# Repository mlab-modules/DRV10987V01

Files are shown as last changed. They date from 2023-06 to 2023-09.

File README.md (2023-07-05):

# DRV10987V01 BLDC motor controller
This MLAB module features the [DRV10987](https://www.ti.com/lit/ds/symlink/drv10987.pdf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) controller by Texas Instruments, designed for sensorless operation of Brushless DC ([BLDC](https://en.wikipedia.org/wiki/Brushless_DC_electric_motor)) and Permanent Magnet Synchronous Motors ([PMSM](https://en.wikipedia.org/wiki/Synchronous_motor#Permanent-magnet)).

 

### Description
The DRV10987 is a three-phase, sensorless, brushless DC motor driver that carries out all necessary functions for ordinary operation of brushless motors. It is a powerful solution that is compact and easy to implement.

This module offers a straightforward way to integrate this potent driver into your project, whether you're a hobbyist, a researcher, or a professional engineer.
Specifications

 *   Power supply ranging from 6.2V to 28V for driving motors with diverse voltage requirements
 *   Provide a continuous current of 2A and peak current of 3A
 *   Can control motor speed based on PWM, analogue, or digital (I2C) input
 *   Contains an FG pin that can be used to monitor motor rotation
 *   Integrated Buck converter at 5V and 100mA for powering peripheral devices
 *   Brushless design that minimizes wear and enables quiet operation
 *   Sensorless commutation for easy installation and maintenance
 *   PWM input frequency up to 100kHz
 *   Communication via I2C interface
 *   Built-in functions for overload and overheat protection

### Applications

This MLAB module equipted with the DRV10987 controller is highly versatile and is ideal for several applications where efficient and reliable control of smaller motors is required. Some of the primary use cases include:

 * **Small Drones and RC Models**: Due to its compact size and efficient operation, the DRV10987 controller is commonly used in the design of smaller drones and radio-controlled models. These vehicles require precise, reliable motor control for stabilization and maneuverability, which this module can adequately provide.
 * **Robotic Systems**: In robotics, precise control of motor speed and direction is essential. The DRV10987 controller's ability to regulate speed based on PWM, analogue, or digital (I2C) input makes it suitable for smaller robotic applications, including hobbyist robots, robotic toys, and educational kits.
 * **Home Appliances**: Small electrical appliances, such as desk fans, can make use of the DRV10987 controller for efficient and quiet operation. The controller's brushless design minimizes wear, which enhances the lifespan and user experience of these devices.
 * **Hobby Projects**: For hobbyists and DIY enthusiasts, this module with the DRV10987 controller is a great tool for various projects requiring control of smaller BLDC or PMSM motors. Its ease of use and versatility make it a valuable component in prototyping and experimentation.

### Installation and Integration
Our MLAB modules are designed to be as straightforward as possible for integration into your project. To connect this module, you only need a standard power supply and an I2C bus for communication with the control system.

### DRV10987

The DRV10987 from Texas Instruments is a three-phase, sensorless motor driver engineered for brushless DC (BLDC) and Permanent Magnet Synchronous Motors (PMSM). It is designed to handle all necessary functions for the routine operation of brushless motors. Capable of delivering a continuous current of 2A and a peak current of 3A, the DRV10987 can control motor speed based on PWM, analogue, or digital (I2C) input. This versatile chip also features an FG pin for monitoring motor rotation and has an integrated Buck converter at 5V and 100mA for powering peripheral devices. With built-in functions for overload and overheat protection, the DRV10987 represents a robust, compact, and efficient solution for a range of applications that require reliable motor control.

Detailed technical information about the DRV10987 controller can be found in the datasheet, available on the manufacturer's website [here](https://www.ti.com/lit/ds/symlink/drv10987.pdf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).

### Schematics



## Availability and Pricing

The MLAB module DRV10987V01 with the DRV10987 controller is commercially produced and sold by Universal [Scientific Technologies s.r.o](https://ust.cz/). For information on availability and pricing, please contact the company directly via email at [info@ust.cz](mailto:info@ust.cz). They will be able to provide the most accurate and up-to-date information regarding your purchase inquiries.

### Conclusion
Regardless of whether you're building a sophisticated robotic system or a simple hobbyist project, this module with the DRV10987 controller from Texas Instruments is a powerful tool for sensorless control of BLDC and PMSM motors.

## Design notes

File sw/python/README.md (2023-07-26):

# Python control class for DRV10987 BLDC driver

This class provides a convenient interface to control a BLDC motor using the DRV10987V01 module, which contains the Texas Instruments DRV10987 motor driver IC. It allows configuration of various parameters and registers to control the motor speed, current, and other functionalities.

The DRV10987V01 module is designed for use with 3-phase sensorless BLDC motors, and this class
simplifies the communication and configuration process, making it easier to drive the motor.

Before using this class, make sure you have properly initialized the communication interface to
communicate with the DRV10987 module using the SMBus interface. For example, you can use the
USBI2C01 module (https://www.mlab.cz/module/USBI2C01) to connect your computer to the driver.

Note:
- Connect the DRV10987V01 module to your motor and power supply according to the module's specifications.
- The methods of this class assume that you have already set up the communication interface (SMBus) correctly.

Example usage:
drv = MLAB_DRV10987()
drv.configure_CONFIG1(RMValue=0b0111011, odpor_vinuti=1)
drv.set_SpeedCtrl(speed=50)  # Set motor speed to 50% (default override=True)
drv.enable_motor()  # Enable motor output
drv.print_status_registers()  # Print the current status registers
drv.disable_motor()  # Disable motor output
"""

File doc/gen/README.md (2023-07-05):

# PCB

Board size: 50.29x40.13 mm (1.98x1.58 inches)

- This is the size of the rectangle that contains the board
- Thickness: 1.6 mm (63 mils)
- Material: FR4
- Finish: None
- Layers: 2
- Copper thickness: 35 µm

Solder mask: TOP / BOTTOM

- Color: Green

Silk screen: TOP / BOTTOM

- Color: White

Stackup:

| Name | Type | Color | Thickness | Material | Epsilon_r | Loss tangent |
|---|---|---|---|---|---|---|
| F.SilkS | Top Silk Screen | | | | | |
| F.Paste | Top Solder Paste | | | | | |
| F.Mask | Top Solder Mask | | 10 | | | |
| F.Cu | copper | | 35 | | | |
| dielectric 1 | core | | 1510 | FR4 | 4.5 | 0.020 |
| B.Cu | copper | | 35 | | | |
| B.Mask | Bottom Solder Mask | | 10 | | | |
| B.Paste | Bottom Solder Paste  | | | | | |
| B.SilkS | Bottom Silk Screen | | | | | |

# Important sizes

Clearance: 0.2 mm (8 mils)

Track width: 0.25 mm (10 mils)

- By design rules: 0.2 mm (8 mils)

Drill: 0.3 mm (12 mils)

- Vias: 0.5 mm (20 mils) [Design: 0.3 mm (12 mils)]
- Pads: 0.3 mm (12 mils)
- The above values are real drill sizes, they add 0.1 mm (4 mils) to plated holes (PTH)

Via: 0.8/0.4 mm (31/16 mils)

- By design rules: 0.4/0.2 mm (16/8 mils)
- Micro via: yes [0.2/0.1 mm (8/4 mils)]
- Buried/blind via: yes
- Total: 46 (thru: 46 buried/blind: 0 micro: 0)

Outer Annular Ring: 0.13 mm (5 mils)

- By design rules: 0.13 mm (5 mils)

Eurocircuits class: 6D
- Using min drill 0.3 mm for an OAR of 0.13 mm

# General stats

Components count: (SMD/THT)

- Top: 0/11 (THT)
- Bottom: 19/0 (SMD)

Defined tracks:

- 0.3 mm (12 mils)
- 0.5 mm (20 mils)

Used tracks:

- 0.25 mm (10 mils) (2) defined: no
- 0.3 mm (12 mils) (67) defined: yes
- 0.4 mm (16 mils) (7) defined: no
- 0.5 mm (20 mils) (15) defined: yes

Defined vias:

Used vias:

- 0.8/0.4 mm (31/16 mils) (Count: 46, Aspect: 2.0 A) defined: no

Holes (excluding vias):

- 0.2 mm (8 mils) (15)
- 0.89 mm (35 mils) (36)
- 1.15 mm (45 mils) (5)
- 3.0 mm (118 mils) (4)

Oval holes:

Drill tools (including vias and computing adjusts and rounding):

- 0.3 mm (12 mils) (15)
- 0.5 mm (20 mils) (46)
- 1.0 mm (39 mils) (36)
- 1.25 mm (49 mils) (5)
- 3.1 mm (122 mils) (4)

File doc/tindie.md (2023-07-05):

If you're seeking a compact, efficient, and easy-to-integrate solution for controlling smaller Brushless DC (BLDC) or Permanent Magnet Synchronous Motors (PMSM), then our MLAB module with the DRV10987 controller from Texas Instruments is for you!

This highly versatile module is perfect for hobbyists, DIY enthusiasts, researchers, and engineers alike. It's designed to handle a continuous current of 2A and a peak current of 3A, making it perfect for smaller-scale applications.

Here's what you can expect from this module:

 * A power supply range from 6.2V to 28V, catering to motors with diverse voltage requirements
 * Flexibility in speed control, with support for PWM, analogue, or digital (I2C) input
 * An integrated Buck converter at 5V and 100mA, perfect for powering peripheral devices
 * An FG pin for convenient monitoring of motor rotation
 * Built-in overload and overheat protection, ensuring safe and reliable operation

Whether you're building a small drone, designing a compact robotic system, working on home appliances, or just experimenting with different projects, this module provides the reliable motor control you need.

And for those interested in medical devices, smaller-scale HVAC systems, or industrial automation applications, this module can be an essential part of your project, offering smooth, precise, and efficient motor control.

Our MLAB module with the DRV10987 controller is not only powerful but also straightforward to integrate into your project. It requires a standard power supply and an I2C bus for communication with the control system. You'll appreciate its ease of use and the versatility it brings to your projects.

Get your hands on our MLAB module with the DRV10987 controller and explore the world of efficient and reliable motor control today.

## Documentation

For detailed information, usage examples, and troubleshooting tips, you can access the official documentation of the MLAB DRV10987V01 module. It's located in our official GitHub repository. Here you'll find comprehensive materials to guide you in harnessing the full potential of this controller module. Please visit the repository at [GitHub](https://github.com/mlab-modules/DRV10987V01) to explore the documentation. This resource will greatly assist both beginners and experienced users in their journey with this versatile module. Let our resources guide your project to success.

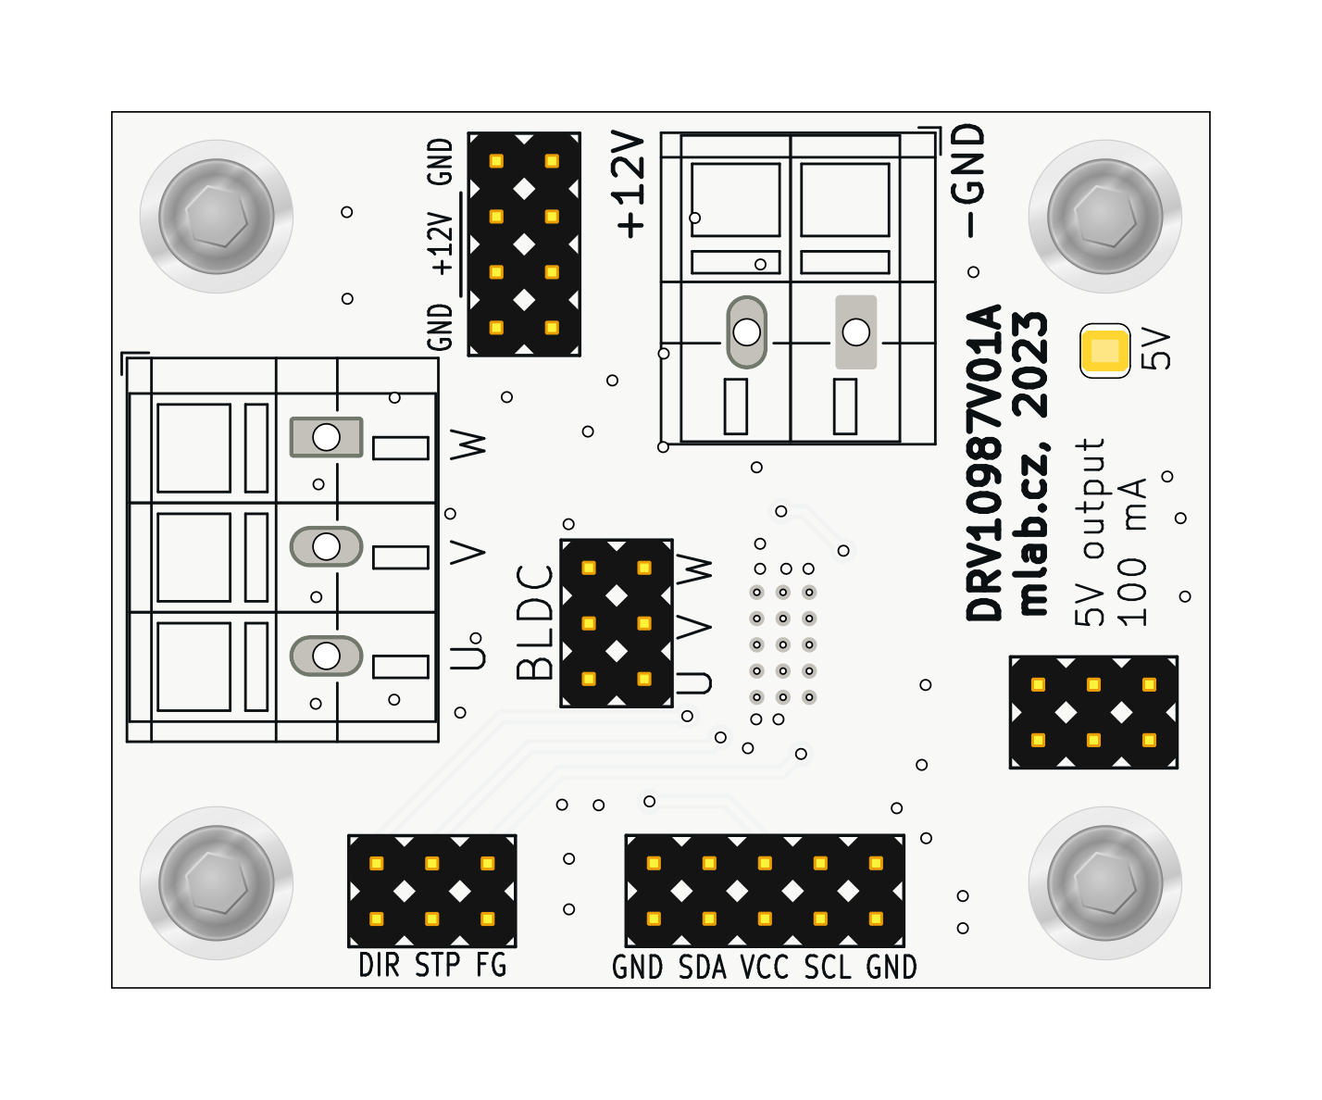
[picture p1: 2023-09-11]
doc/gen/img/DRV10987V01-top.png

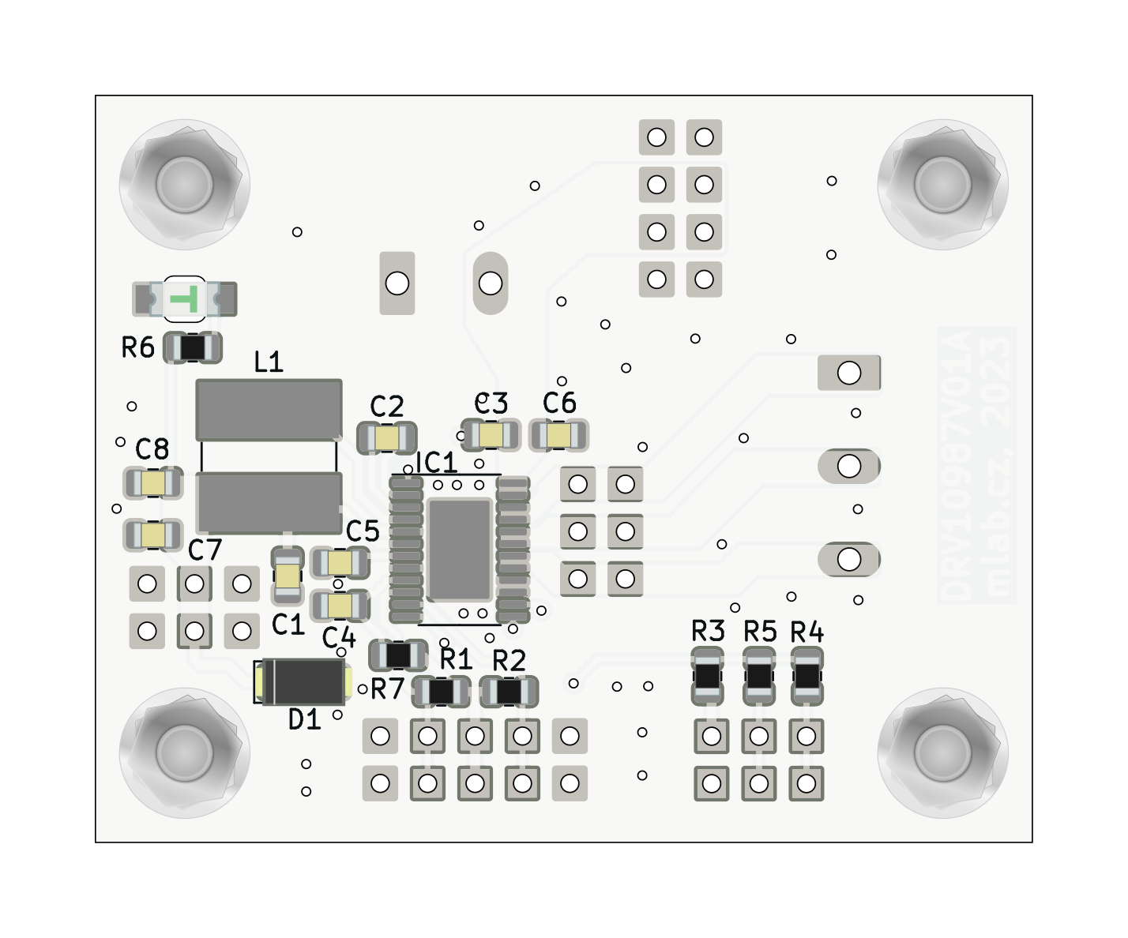
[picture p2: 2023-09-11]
doc/gen/img/DRV10987V01-bottom.png

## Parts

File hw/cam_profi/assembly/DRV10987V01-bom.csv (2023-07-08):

Component | Description | Part | References | Value | Footprint | Quantity Per PCB | Datasheet | ust_id | arrow part number | arrow price/stock | height | manufacturer_name | manufacturer_part_number | mouser part number | mouser price/stock
1 | Unpolarized capacitor, small symbol | C_Small | C2 | 10nF | C_0805_2012Metric | 1 | ~ | 5c70984712875079b91f8b49
2 | Unpolarized capacitor, small symbol | C_Small | C3 | 100nF | C_0805_2012Metric | 1 | ~ | 5c70984712875079b91f8b4c
3 |  | C_Small-Device-ISM02A-rescue | C8 | 100nF | C_0805_2012Metric | 1 |  | 5c70984712875079b91f8b4c
4 | Unpolarized capacitor, small symbol | C_Small | C4C5 | 1uF | C_0805_2012Metric | 2 | ~ | 5c70984712875079b91f8b50
5 | Unpolarized capacitor, small symbol | C_Small | C1C6 | 10uF | C_0805_2012Metric | 2 | ~ | 5c70984712875079b91f8b53
6 |  | C_Small-Device-ISM02A-rescue | C7 | 10uF | C_0805_2012Metric | 1 |  | 5c70984712875079b91f8b53
7 |  | D_ZENER-MLAB_D | D1 | BZV55C-5,6V | D_SMA | 1 |  | 5c70984512875079b91f88b2
8 | Light emitting diode | LED | D2 | GREEN | LED_1206_2 | 1 | ~ | 5c70984412875079b91f8895
9 | 12-V, 3-Phase, Sensorless BLDC Motor Controller | DRV10975PWPR | IC1 | DRV10987DPWPR | TSSOP-24_4.4x7.8mm_P0.65mm_PowerPAD | 1 | https://www.ti.com/lit/ds/symlink/drv10975.pdf?ts=1619503349914 | 649ebe2a76c82a1d3b578220 | DRV10975PWPR | https://www.arrow.com/en/products/drv10975pwpr/texas-instruments?region=nac | 1.2 | Texas Instruments | DRV10987DPWPR | 595-DRV10987DPWPR | https://www.mouser.co.uk/ProductDetail/Texas-Instruments/DRV10975PWPR?qs=OfeFRKQgECjjJ%252BDg0AsiSg%3D%3D
10 | 2x03 2.54 mm pitch header, 2 pins next to each other are connected | HEADER_2x03_PARALLEL | J5 | AUX | Straight_2x03 | 1
11 | 2x04 2.54 mm pitch header, 2 pins next to each other are connected | HEADER_2x04_PARALLEL | J3 | HEADER_2x04_PARALLEL | Straight_2x04 | 1
12 | 2x05 2.54 mm pitch header, 2 pins next to each other are connected | HEADER_2x05_PARALLEL | J2 | I2C | Straight_2x05 | 1
13 | 2x03 2.54 mm pitch header, 2 pins next to each other are connected | HEADER_2x03_PARALLEL | J6 | MOTOR | Straight_2x03 | 1
14 | 2x03 2.54 mm pitch header, 2 pins next to each other are connected | HEADER_2x03_PARALLEL | J10 | PWR | Straight_2x03 | 1
15 | 1x02 2.54 mm pitch header | HEADER_1x02 | J11 | WAGO | TerminalBlock_WAGO_236-102_1x02_P5.00mm_45Degree | 1
16 | 1x03 2.54 mm pitch header | HEADER_1x03 | J12 | WAGO | TerminalBlock_WAGO_236-103_1x03_P5.00mm_45Degree | 1
17 | Inductor | L | L1 | 47uH DE0703-47 | L_Ferrocore_DLG-0703 | 1 | ~ | 5c70984712875079b91f8b69 |  |  |  |  | DE0703-47
18 | Resistor, small symbol | R_Small | R7 | 100R | R_0805_2012Metric | 1 | ~ | 5c70984512875079b91f8977
19 | Resistor, small symbol | R_Small | R6 | 160R | R_0805_2012Metric | 1 | ~ | 5c70984512875079b91f897b
20 | Resistor, small symbol | R_Small | R1R2R3 | 4k7 | R_0805_2012Metric | 3 | ~ | 5c70984612875079b91f8995

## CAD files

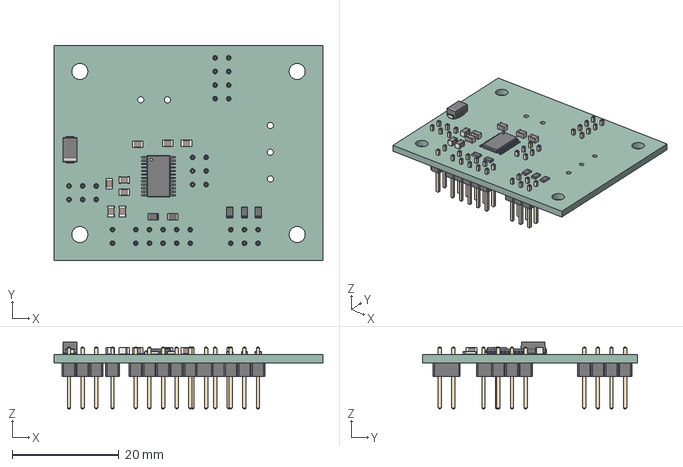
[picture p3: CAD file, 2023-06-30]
doc/gen/DRV10987V01.step
50.3 x 40.1 x 12.4 mm
tmpklivth97 PCB

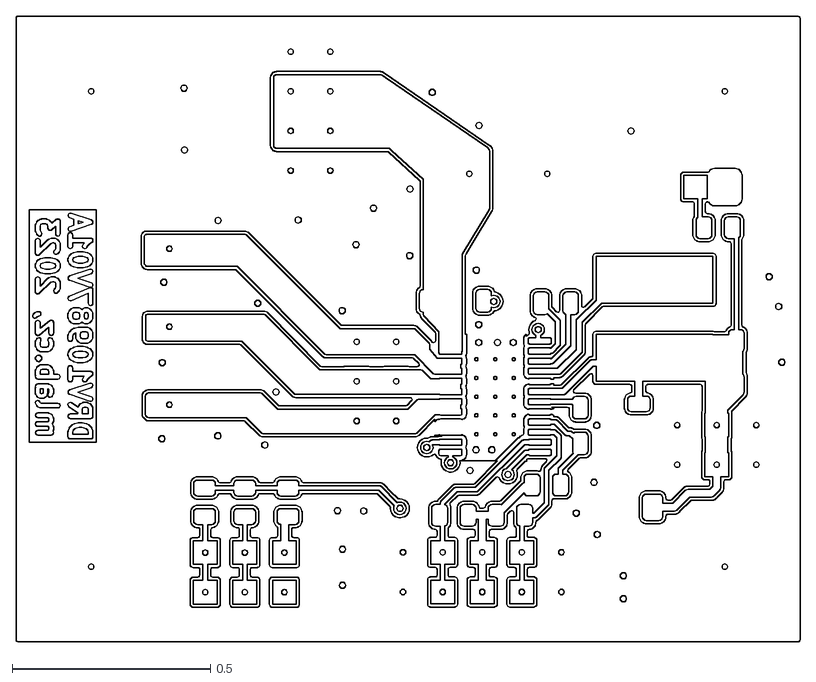
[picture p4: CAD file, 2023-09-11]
doc/gen/dxf/DRV10987V01-B_Cu.dxf
1.98 x 1.58

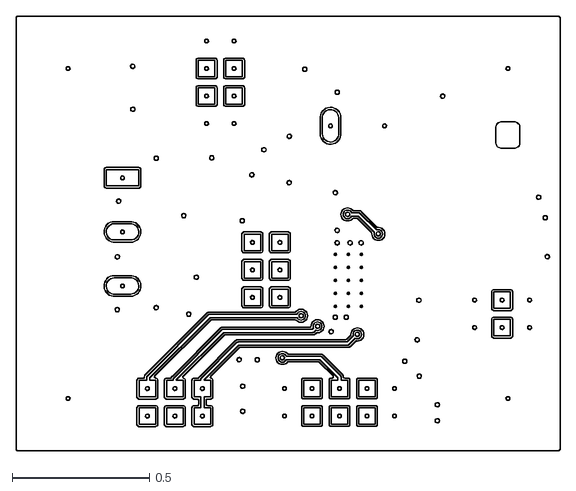
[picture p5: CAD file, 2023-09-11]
doc/gen/dxf/DRV10987V01-F_Cu.dxf
1.98 x 1.58

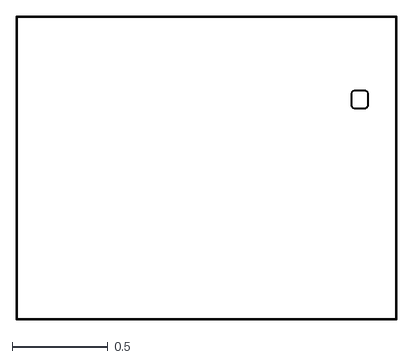
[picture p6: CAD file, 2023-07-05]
doc/gen/dxf/DRV10987V01-Edge_Cuts.dxf
1.99 x 1.59

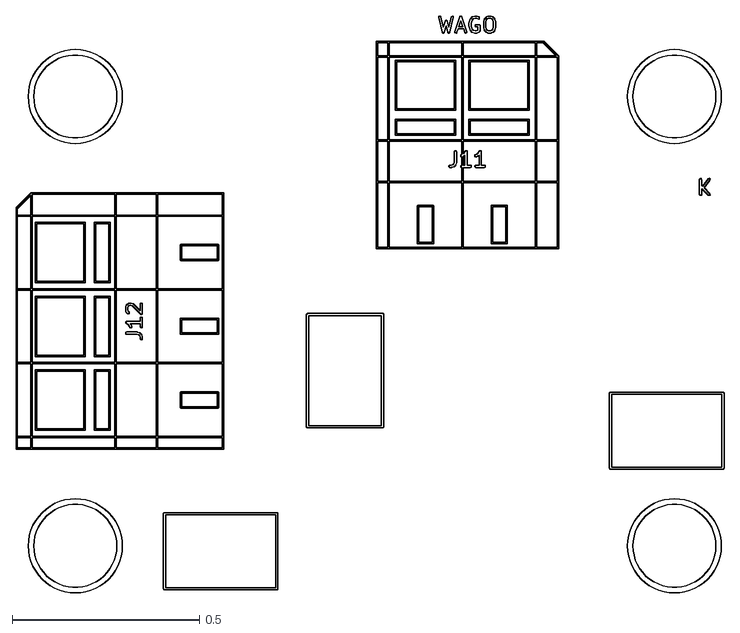
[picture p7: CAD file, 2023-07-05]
doc/gen/dxf/DRV10987V01-F_Fab.dxf
1.89 x 1.54

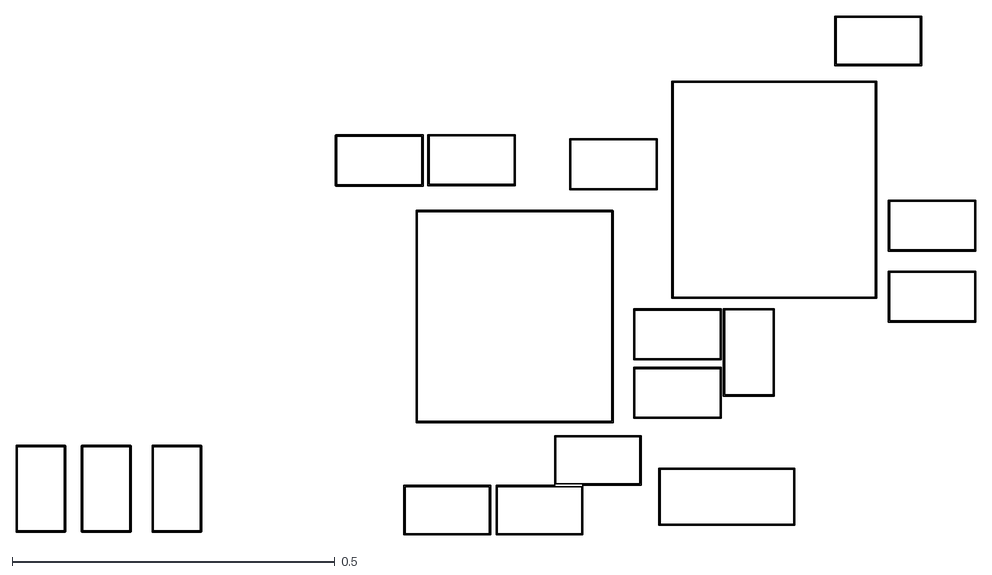
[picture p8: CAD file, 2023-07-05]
doc/gen/dxf/DRV10987V01-B_Courtyard.dxf
1.49 x 0.803

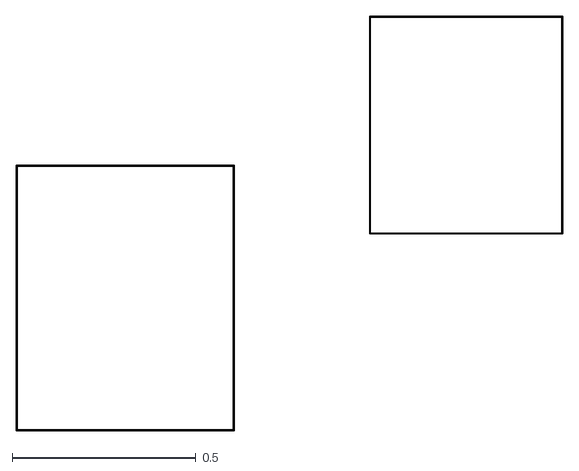
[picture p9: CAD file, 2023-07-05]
doc/gen/dxf/DRV10987V01-F_Courtyard.dxf
1.49 x 1.13

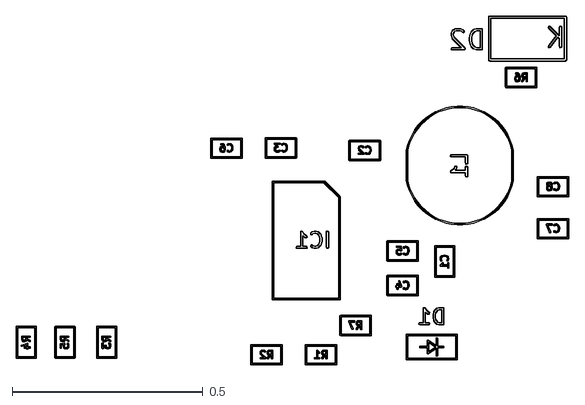
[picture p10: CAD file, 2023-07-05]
doc/gen/dxf/DRV10987V01-B_Fab.dxf
1.45 x 0.914

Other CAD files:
doc/gen/dxf/DRV10987V01-User_9.dxf
doc/gen/dxf/DRV10987V01-User_Comments.dxf
doc/gen/dxf/DRV10987V01-User_5.dxf
doc/gen/dxf/DRV10987V01-F_Adhesive.dxf
doc/gen/dxf/DRV10987V01-Margin.dxf
doc/gen/dxf/DRV10987V01-User_7.dxf
doc/gen/dxf/DRV10987V01-User_4.dxf
doc/gen/dxf/DRV10987V01-User_2.dxf
doc/gen/dxf/DRV10987V01-User_8.dxf
doc/gen/dxf/DRV10987V01-User_Eco2.dxf
doc/gen/dxf/DRV10987V01-B_Adhesive.dxf
doc/gen/dxf/DRV10987V01-B_Mask.dxf
doc/gen/dxf/DRV10987V01-B_Paste.dxf
doc/gen/dxf/DRV10987V01-B_Silkscreen.dxf
doc/gen/dxf/DRV10987V01-F_Mask.dxf
doc/gen/dxf/DRV10987V01-F_Paste.dxf
doc/gen/dxf/DRV10987V01-F_Silkscreen.dxf
doc/gen/dxf/DRV10987V01-User_1.dxf
doc/gen/dxf/DRV10987V01-User_3.dxf
doc/gen/dxf/DRV10987V01-User_6.dxf
doc/gen/dxf/DRV10987V01-User_Drawings.dxf
doc/gen/dxf/DRV10987V01-User_Eco1.dxf

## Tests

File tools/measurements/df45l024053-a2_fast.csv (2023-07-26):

X | CH1 | CH2 | Start | Increment
Sequence | Volt | Volt | -1.400000e-02 | 2.000000e-05
0 | 3.360000e+00 | 4.400000e+00
1 | 3.040000e+00 | 4.640000e+00
2 | 3.360000e+00 | 4.400000e+00
3 | 3.040000e+00 | 4.640000e+00
4 | 3.200000e+00 | 4.480000e+00
5 | 2.960000e+00 | 4.720000e+00
6 | 2.400000e+00 | 4.160000e+00
7 | 3.600000e+00 | 5.200000e+00
8 | 2.960000e+00 | 4.800000e+00
9 | 2.640000e+00 | 4.400000e+00
10 | 2.800000e+00 | 4.640000e+00
11 | 2.560000e+00 | 4.800000e+00
12 | 2.400000e+00 | 4.880000e+00
13 | 2.800000e+00 | 4.480000e+00
14 | 2.560000e+00 | 4.640000e+00
15 | 2.320000e+00 | 4.800000e+00
16 | 2.480000e+00 | 4.800000e+00
17 | 2.160000e+00 | 4.640000e+00
18 | 2.320000e+00 | 4.800000e+00
19 | 2.000000e+00 | 4.640000e+00
20 | 2.160000e+00 | 4.800000e+00
21 | 1.920000e+00 | 4.640000e+00
22 | 2.000000e+00 | 4.800000e+00
23 | 1.760000e+00 | 4.560000e+00
24 | 1.840000e+00 | 4.560000e+00
25 | 1.600000e+00 | 4.800000e+00
26 | 1.680000e+00 | 4.720000e+00
27 | 1.440000e+00 | 4.480000e+00
28 | 1.520000e+00 | 4.480000e+00
29 | 1.280000e+00 | 4.720000e+00
30 | 1.440000e+00 | 4.640000e+00
31 | 1.120000e+00 | 4.400000e+00
32 | 1.200000e+00 | 4.560000e+00
33 | 8.800000e-01 | 4.400000e+00
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

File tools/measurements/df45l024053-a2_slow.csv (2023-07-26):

X | CH1 | CH2 | Start | Increment
Sequence | Volt | Volt | -7.000000e-02 | 1.000000e-04
0 | 1.500000e+00 | 8.200000e-01
1 | 1.180000e+00 | 5.400000e-01
2 | 1.500000e+00 | 8.200000e-01
3 | 1.180000e+00 | 5.400000e-01
4 | 1.160000e+00 | 6.000000e-01
5 | 1.740000e+00 | 1.120000e+00
6 | 1.260000e+00 | 7.000000e-01
7 | 1.500000e+00 | 9.800000e-01
8 | 1.140000e+00 | 6.800000e-01
9 | 1.580000e+00 | 1.100000e+00
10 | 1.380000e+00 | 9.000000e-01
11 | 1.320000e+00 | 1.000000e+00
12 | 1.460000e+00 | 1.120000e+00
13 | 1.260000e+00 | 9.200000e-01
14 | 1.340000e+00 | 1.020000e+00
15 | 1.260000e+00 | 1.100000e+00
16 | 1.200000e+00 | 1.020000e+00
17 | 1.440000e+00 | 1.240000e+00
18 | 1.260000e+00 | 1.100000e+00
19 | 1.180000e+00 | 1.180000e+00
20 | 1.320000e+00 | 1.060000e+00
21 | 1.020000e+00 | 1.360000e+00
22 | 1.160000e+00 | 1.180000e+00
23 | 1.080000e+00 | 1.260000e+00
24 | 1.120000e+00 | 1.220000e+00
25 | 1.040000e+00 | 1.280000e+00
26 | 8.400000e-01 | 1.100000e+00
27 | 1.180000e+00 | 1.440000e+00
28 | 1.060000e+00 | 1.400000e+00
29 | 8.200000e-01 | 1.200000e+00
30 | 1.060000e+00 | 1.420000e+00
31 | 8.600000e-01 | 1.240000e+00
32 | 9.400000e-01 | 1.320000e+00
33 | 8.400000e-01 | 1.420000e+00
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

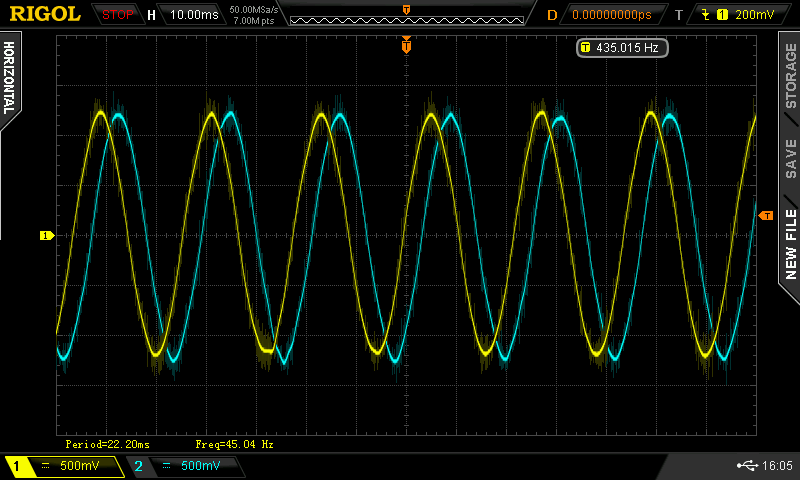
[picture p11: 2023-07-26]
tools/measurements/df45m024053-a2_slow.png

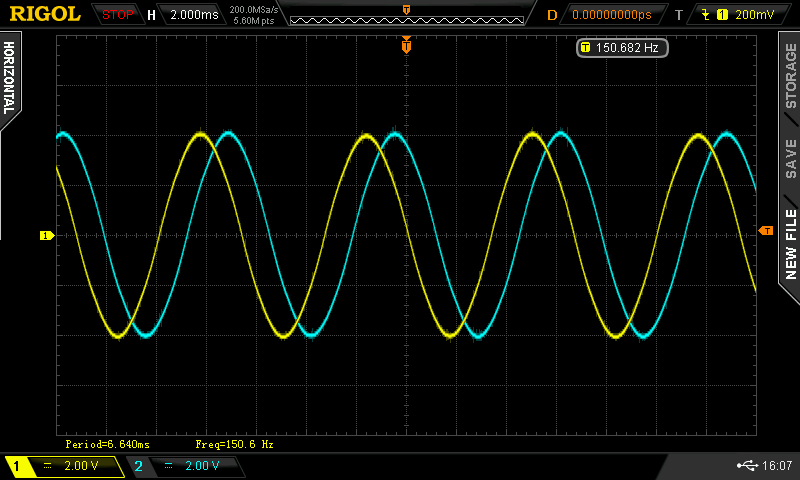
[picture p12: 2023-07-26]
tools/measurements/df45m024053-a2_fast.png

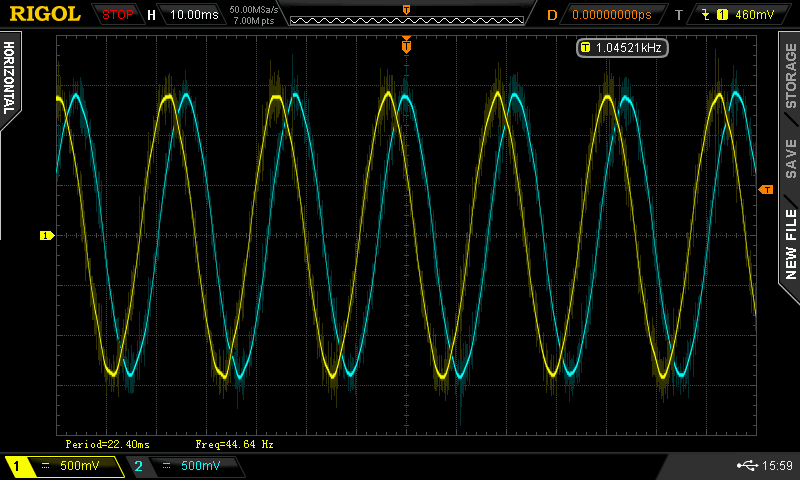
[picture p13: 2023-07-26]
tools/measurements/df45l024053-a2_slow.png

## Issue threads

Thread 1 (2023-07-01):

Silkscreen design

kaklik, 2023-07-01:
Aktuální návrh modulu obsahuje mnoho velikostí a tlouštěk čar v silkscreenu. Nevypadá to dobře a pro větší výrobu by to bylo vhodné upravit.

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

ChroustJan, 2023-07-04:
Já bych čekal že tohle byl záměr @roman-dvorak. Z mého pohledu to má nějakou hlavu a patu.

roman-dvorak, 2023-07-12:
Různé velikosti popisků mají svou podstatu (Jediné, co bych upravil jsou možná popisky "+12V" "-GND" vedle wago konektorů - ale i tak mi to dává smysl)

Před tím by ale bylo dobré alespoň jeden modul vidět plně osazený s wago konektory.

Co se týče silkscreenu, tak bych tam především upravil popisky "+12V" něčím jako "PWR", protože driver podporuje výkonové napájení 6.2 - 28V. S tím souvisí, že je potřeba zkontrolovat, že všechny okolní součástky jsou schopné pracovat v tomto napěťovém rozsahu.

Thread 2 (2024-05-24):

Too low power protection diode D1

kaklik, 2024-05-24:
D1 is a zener protection diode on input voltage, but the power rating is unsuitable for this application, where voltage spikes easily exceed the minimum threshold of 5.2V.

The diode needs to be changed to a more robust type. According to the datasheet, there is probably no requirement to be the zener type, because the SW pin windstands up to 23V and is also the output. Therefore the diode protects only a polarity in the situation where someone connects the voltage to the regulator output.

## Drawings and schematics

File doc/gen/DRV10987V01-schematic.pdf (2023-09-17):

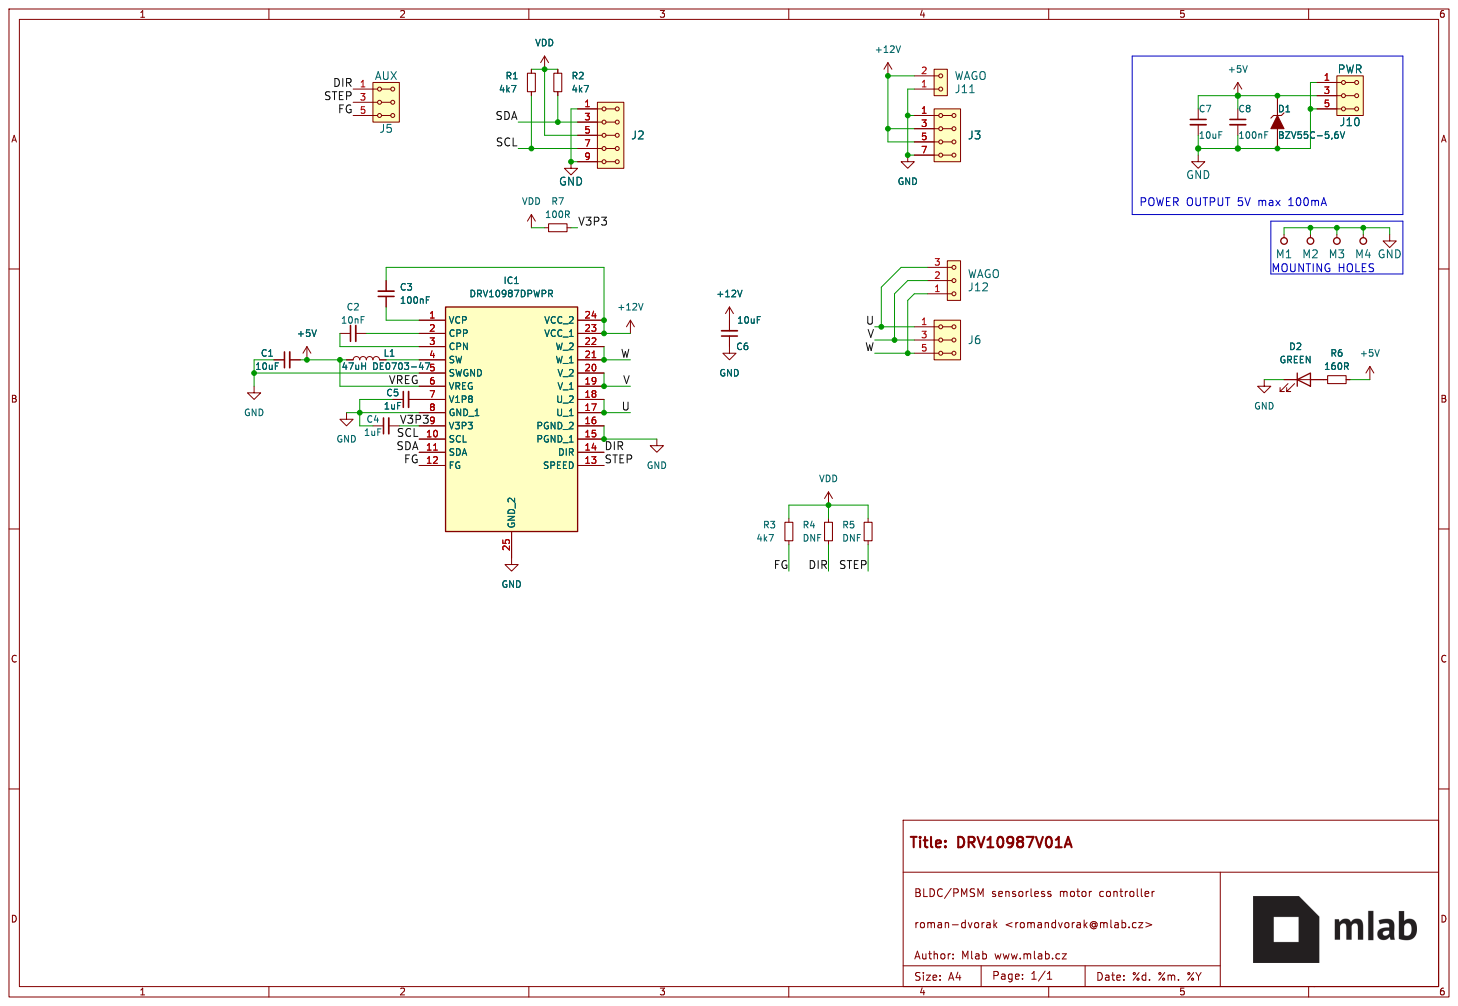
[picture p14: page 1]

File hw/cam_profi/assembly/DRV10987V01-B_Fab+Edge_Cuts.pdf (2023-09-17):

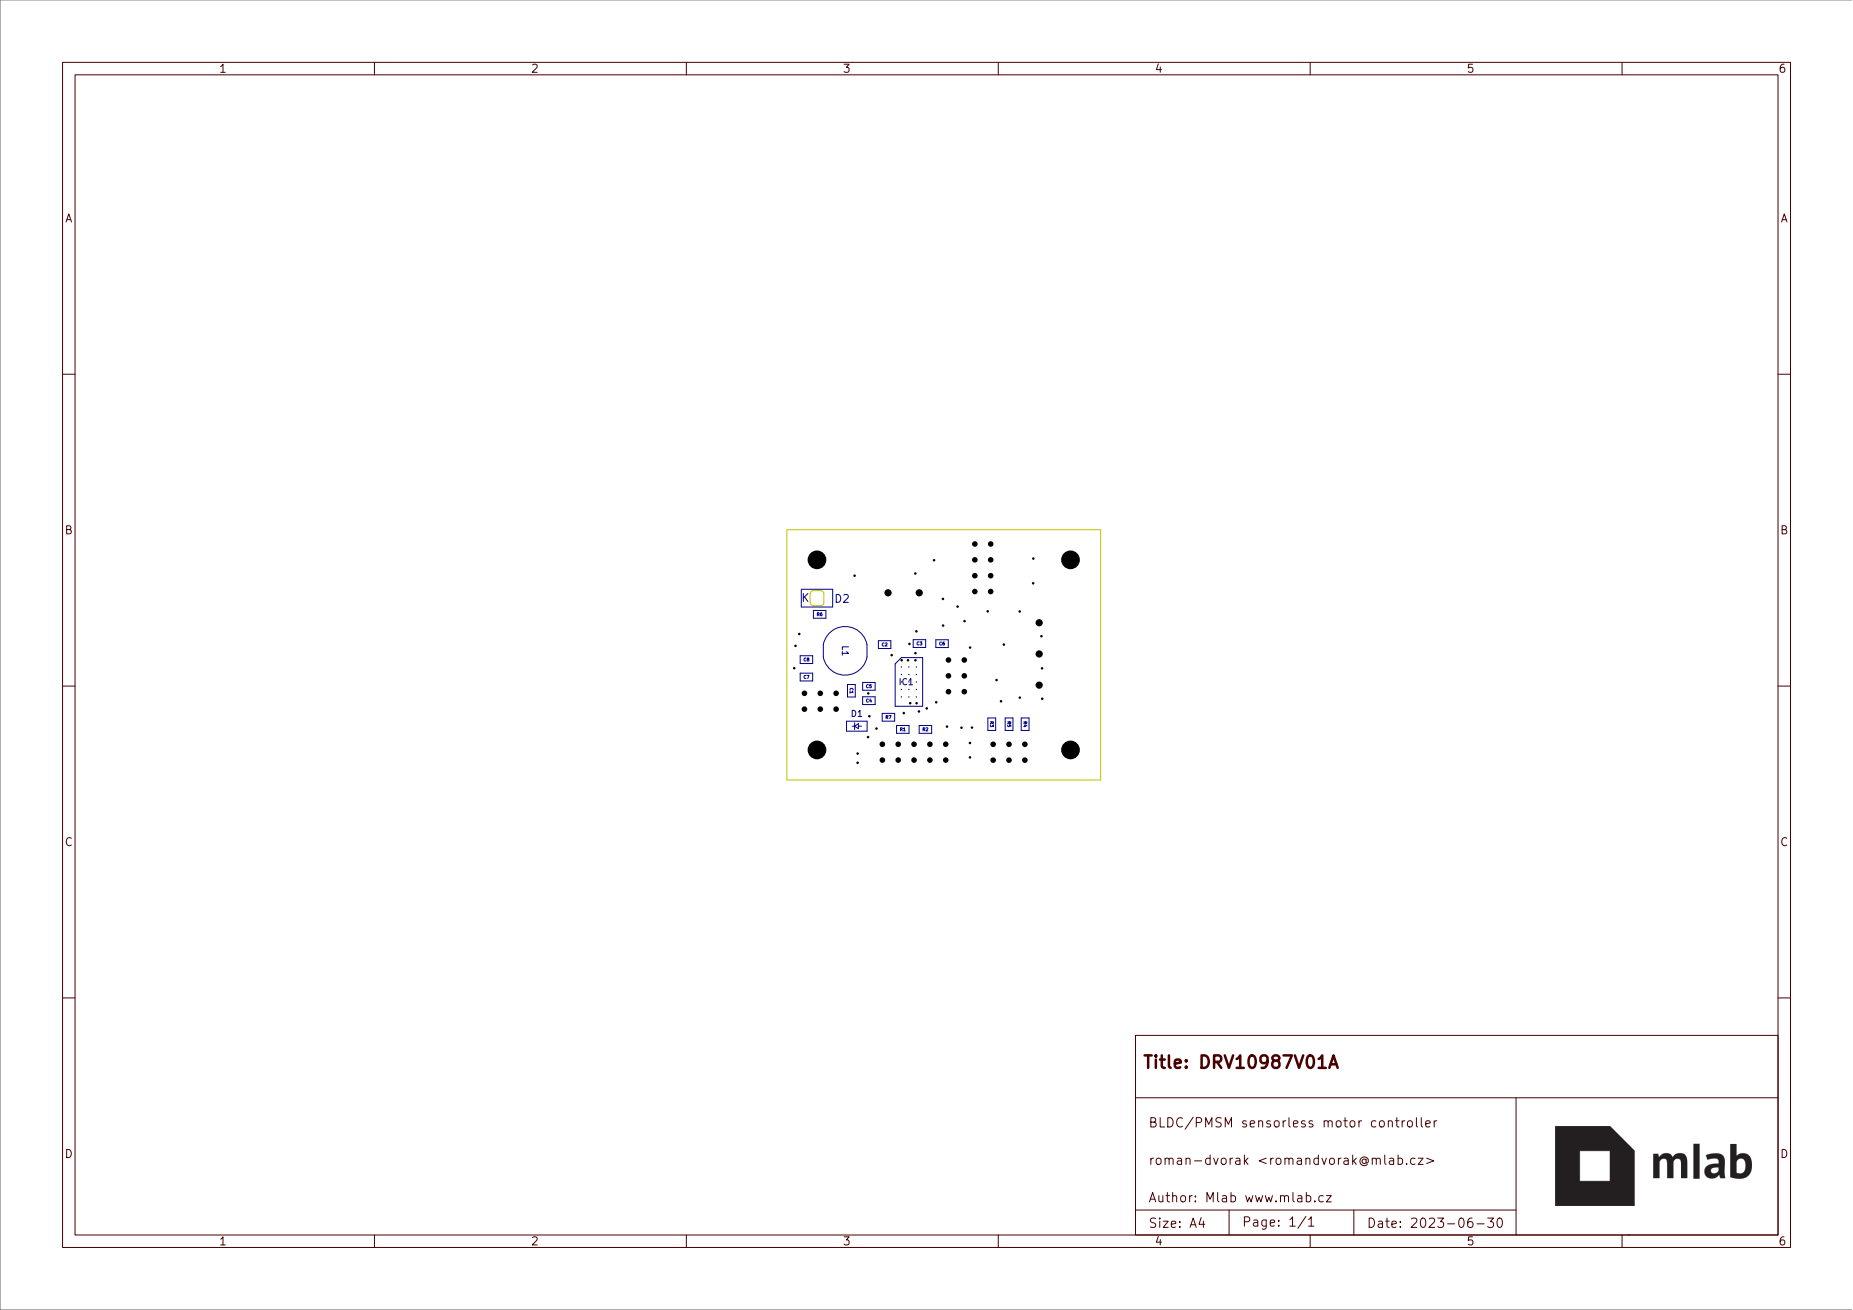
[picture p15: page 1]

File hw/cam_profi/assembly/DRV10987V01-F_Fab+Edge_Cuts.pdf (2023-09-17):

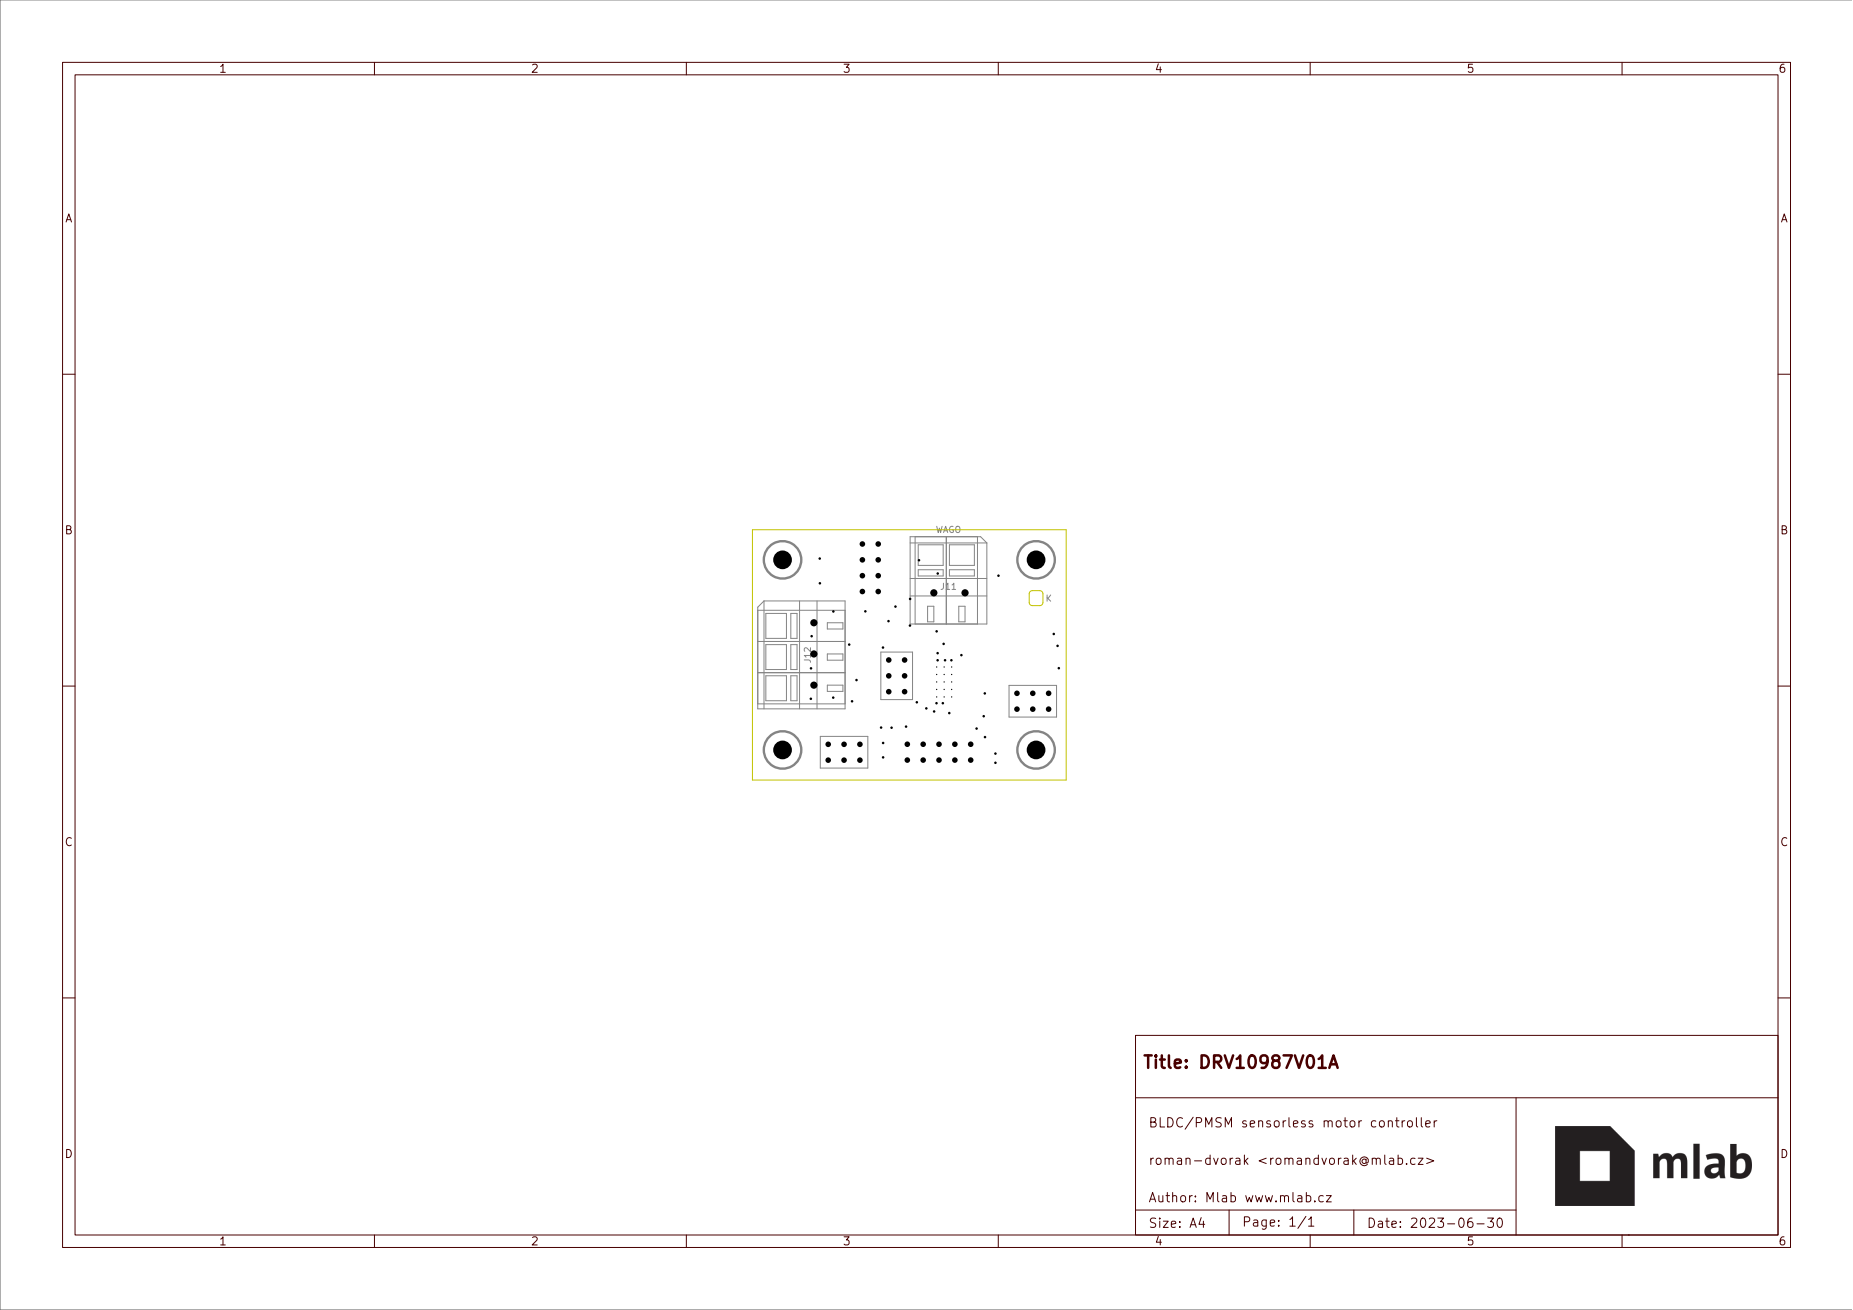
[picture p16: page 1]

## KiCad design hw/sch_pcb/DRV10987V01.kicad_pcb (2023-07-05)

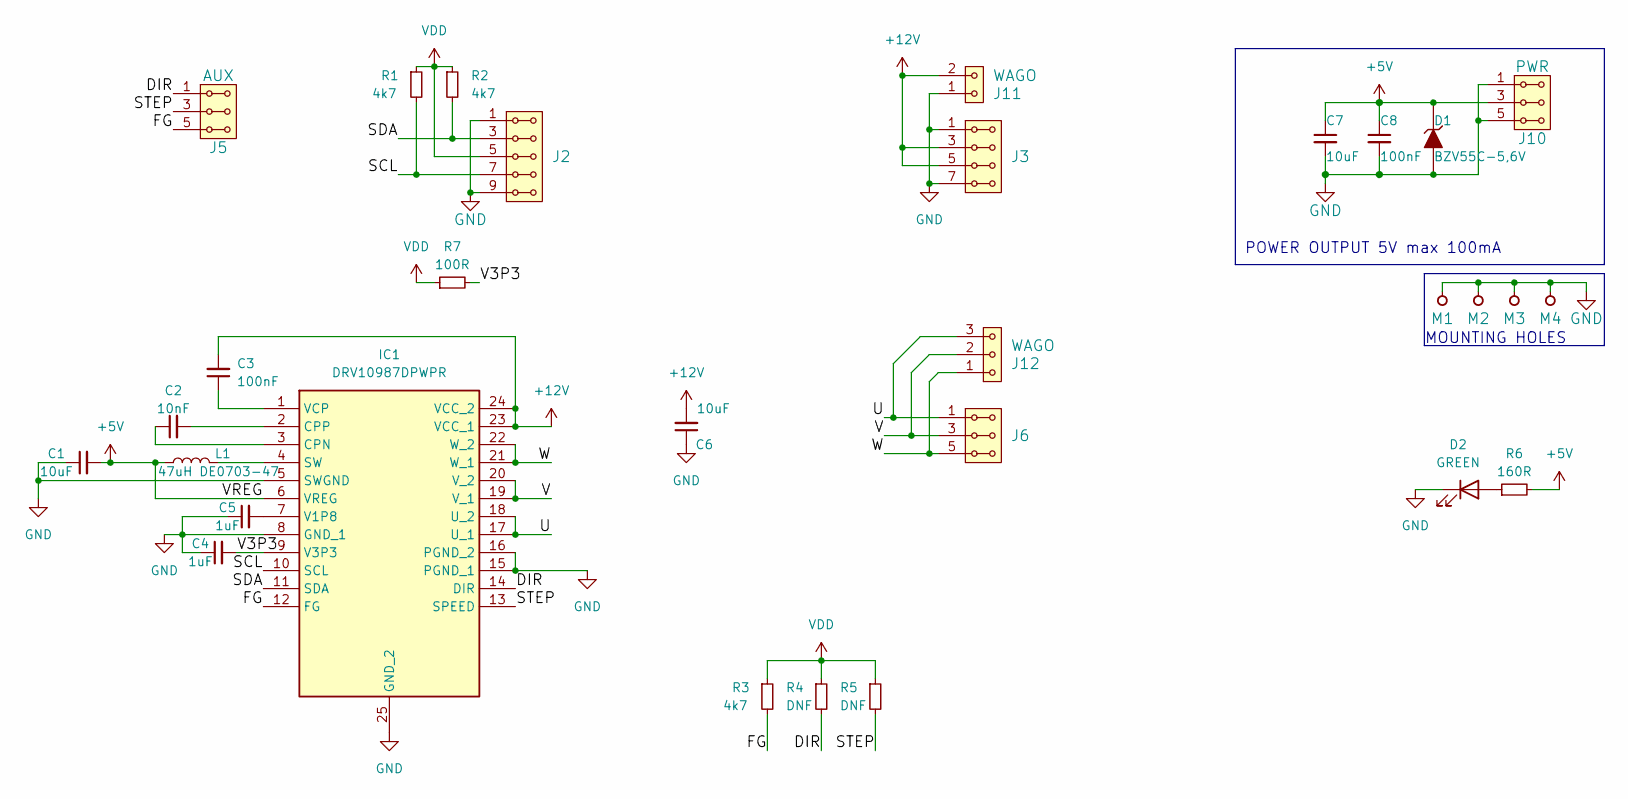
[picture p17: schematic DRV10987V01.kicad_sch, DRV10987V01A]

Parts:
C1, C6, C7: 10uF; C_0805_2012Metric
C2: 10nF; C_0805_2012Metric
C3, C8: 100nF; C_0805_2012Metric
C4, C5: 1uF; C_0805_2012Metric
D1: BZV55C-5,6V; D_SMA
D2: GREEN; LED_1206_2
IC1: DRV10987DPWPR; TSSOP-24_4.4x7.8mm_P0.65mm_PowerPAD; Manufacturer_Part_Number DRV10987DPWPR; Mouser Part Number 595-DRV10987DPWPR
J2: I2C; Straight_2x05
J3: HEADER_2x04_PARALLEL; Straight_2x04
J5: AUX; Straight_2x03
J6: MOTOR; Straight_2x03
J10: PWR; Straight_2x03
J11: WAGO; TerminalBlock_WAGO_236-102_1x02_P5.00mm_45Degree
J12: WAGO; TerminalBlock_WAGO_236-103_1x03_P5.00mm_45Degree
L1: 47uH DE0703-47; L_Ferrocore_DLG-0703; Manufacturer_Part_Number DE0703-47
M1, M2, M3, M4: HOLE M3; MountingHole_3mm
R1, R2, R3: 4k7; R_0805_2012Metric
R4, R5: DNF; R_0805_2012Metric
R6: 160R; R_0805_2012Metric
R7: 100R; R_0805_2012Metric

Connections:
+5V: C1.2, C7.1, C8.1, D1.1 (K), IC1.6 (VREG), J10.3, J10.4, L1.1, R6.2
+12V: C3.2, C6.2, IC1.23 (VCC_1), IC1.24 (VCC_2), J3.3, J3.4, J3.5, J3.6, J11.2
/DIR: IC1.14 (DIR), J5.1, J5.2, R4.2
/FG: IC1.12 (FG), J5.5, J5.6, R3.2
/SCL: IC1.10 (SCL), J2.7, J2.8, R1.2
/SDA: IC1.11 (SDA), J2.3, J2.4, R2.2
/STEP: IC1.13 (SPEED), J5.3, J5.4, R5.2
/U: IC1.17 (U_1), IC1.18 (U_2), J6.1, J6.2, J12.3
/V: IC1.19 (V_1), IC1.20 (V_2), J6.3, J6.4, J12.2
/V3P3: C4.2, IC1.9 (V3P3), R7.2
/W: IC1.21 (W_1), IC1.22 (W_2), J6.5, J6.6, J12.1
GND: C1.1, C4.1, C5.1, C6.1, C7.2, C8.2, D1.2 (A), D2.1 (K), IC1.5 (SWGND), IC1.8 (GND_1), IC1.15 (PGND_1), IC1.16 (PGND_2), IC1.25 (GND_2), J2.1, J2.2, J2.9, J2.10, J3.1, J3.2, J3.7, J3.8, J10.1, J10.2, J10.5, J10.6, J11.1, M1.1, M2.1, M3.1, M4.1
unnamed: D2.2 (A), R6.1
unnamed: C2.1, IC1.3 (CPN)
unnamed: C2.2, IC1.2 (CPP)
unnamed: IC1.4 (SW), L1.2
unnamed: C5.2, IC1.7 (V1P8)
unnamed: C3.1, IC1.1 (VCP)
VDD: J2.5, J2.6, R1.1, R2.1, R3.1, R4.1, R5.1, R7.1

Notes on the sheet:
POWER OUTPUT 5V max 100mA
MOUNTING HOLES

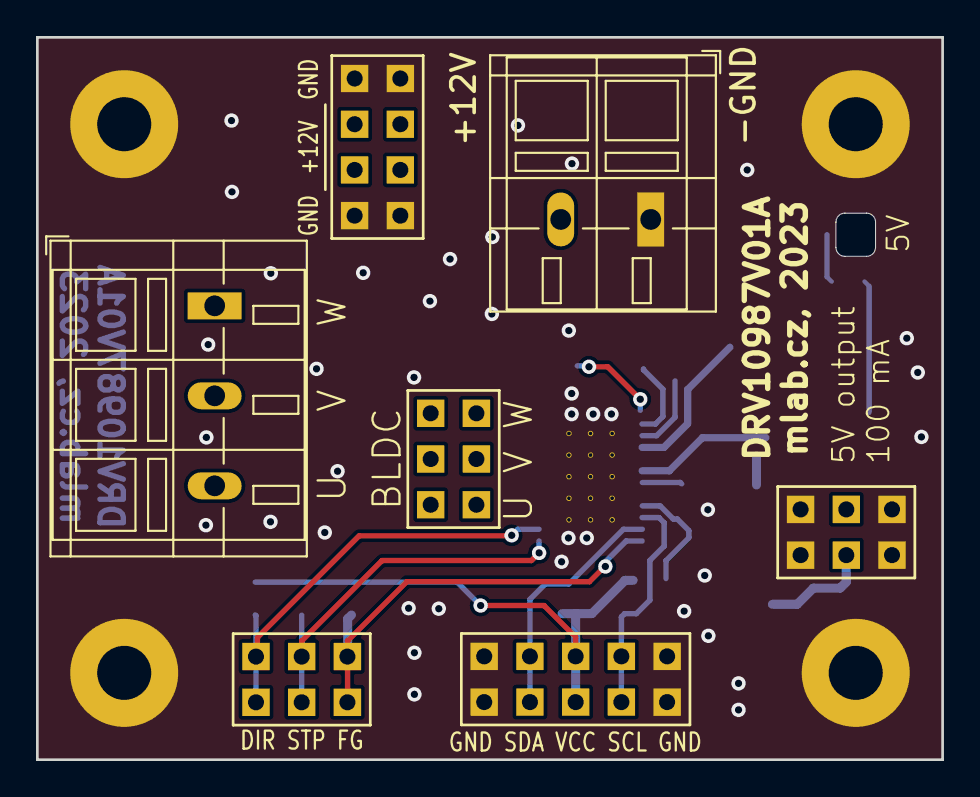
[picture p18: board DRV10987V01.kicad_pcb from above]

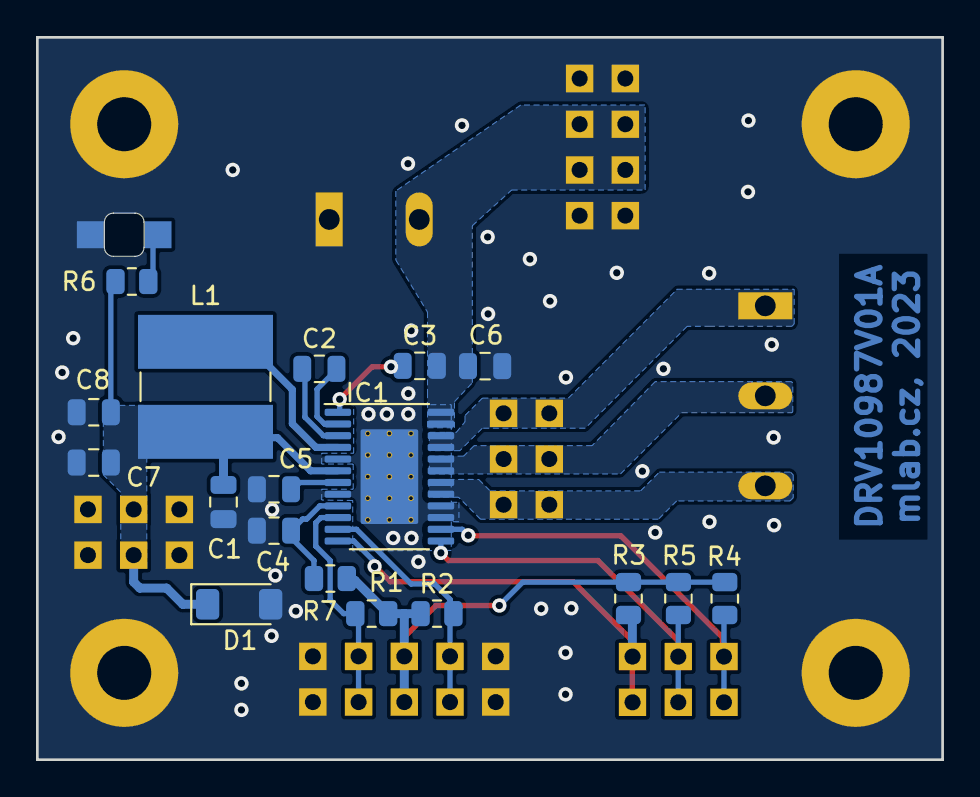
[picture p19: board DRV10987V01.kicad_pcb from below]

Board: 2 copper layers, 50.3 x 40.1 mm, 30 parts (19 on the bottom side), 19 nets.

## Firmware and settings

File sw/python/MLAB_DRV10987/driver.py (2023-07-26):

#! /usr/bin/python3

import smbus2 as smbus
import time

class MLAB_DRV10987():
    """
    Class for controlling BLDC motor using the DRV10987V01 MLAB module.
    https://www.mlab.cz/module/DRV10987V01

    This class provides a convenient interface to control a BLDC motor using the DRV10987V01 module,
    which contains the Texas Instruments DRV10987 motor driver IC. It allows configuration of various
    parameters and registers to control the motor speed, current, and other functionalities.

    The DRV10987V01 module is designed for use with 3-phase sensorless BLDC motors, and this class
    simplifies the communication and configuration process, making it easier to drive the motor.

    Before using this class, make sure you have properly initialized the communication interface to
    communicate with the DRV10987 module using the SMBus interface. For example, you can use the
    USBI2C01 module (https://www.mlab.cz/module/USBI2C01) to connect your computer to the driver.

    Note:
    - Connect the DRV10987V01 module to your motor and power supply according to the module's specifications.
    - The methods of this class assume that you have already set up the communication interface (SMBus) correctly.
    """

    DRVADDR = 0b1010010
    FaultReg = 0x00
    MotorSpeed = 0x01
    MotorPeriod = 0x02
    MotorXt = 0x03
    MotorCurrent = 0x04
    IPDPosition = 0x05
    SupplyVoltage = 0x05
    SpeedCmd = 0x06
    SpdCmdBuffer = 0x06
    AnalogInLvl = 0x07
    DeviceId = 0x08
    SpeedCtrl = 0x30
    EepromProgramming1 = 0x31
    EepromProgramming2 = 0x32
    EepromProgramming3 = 0x33
    EepromProgramming4 = 0x34
    EepromProgramming5 = 0x35
    EepromProgramming6 = 0x36
    EECTRL = 0x60
    CONFIG1 = 0x90
    CONFIG2 = 0x91
    CONFIG3 = 0x92
    CONFIG4 = 0x93
    CONFIG5 = 0x94
    CONFIG6 = 0x95
    CONFIG7 = 0x96

    EepromProgramming5_ShadowMode = 1 << 12  # Bit 12 for enabling shadow mode in EepromProgramming5

    def __init__(self, bus: smbus.SMBus = smbus.SMBus(1), addr: int = 0b1010010, initialize: bool = True, enable_motor: bool = True, shadow: bool = True) -> None:
        """
        Initialize the DRV10xx motor driver class.

        Args:
            bus (smbus.SMBus, optional): The I2C bus object for communication. Default is /dev/i2c-1.
            addr (int, optional): The address of the device. Default is 0b1010010.
        """
        self.bus = bus
        self.addr = addr

        if not shadow:
            raise "Non shadow mode is not supported yet" # type: ignore
        else:
            self.set_shadow_mode()
        
        if initialize:
            self.disable_motor()
            time.sleep(1)
            self.configure_CONFIG1()
            self.configure_CONFIG2()
            self.configure_CONFIG3()
            self.configure_CONFIG4()
            self.configure_CONFIG5()
            self.configure_CONFIG6()
            self.configure_CONFIG7()

        if enable_motor:
            self.enable_motor()

    def _crop(self, val, min, max):
        """
        Crop the value to be within the given range.

        Args:
            val (float): The value to be cropped.
            min (float): The minimum value of the range.
            max (float): The maximum value of the range.

        Returns:
            float: The cropped value within the range.
        """
        if val < min:
            return min
        elif val > max:
            return max
        else:
            return val

    def _write_config_register(self, reg: int, bit_values: dict) -> None:
        """
        Write the configuration register with the specified bit values.

        Args:
            reg (int): The address of the configuration register.
            bit_values (dict): A dictionary with bit positions as keys and their values.

        Note:
            The `bit_values` dictionary should contain the bit positions as keys (0 to 15) and
            the corresponding bit values (0 or 1) to be written to the register.
        """
        value = 0
        for bit_pos, bit_value in bit_values.items():
            value |= bit_value << bit_pos
        self.write(reg, value)

    def read(self, reg: int) -> int:
        """
        Read a 16-bit value from the specified register address.

        Args:
            reg (int): The address of the register to read from.

        Returns:
            int: The 16-bit value read from the register.
        """
        # Implement the logic to read from the I2C bus
        a = self.bus.read_i2c_block_data(self.addr, reg, 2)
        return (a[1]) | (a[0]) << 8
    
    def write(self, reg: int, value: int) -> None:
        """
        Write a 16-bit value to the specified register address.

        Args:
            reg (int): The address of the register to write to.
            value (int): The 16-bit value to be written to the register.
        """
        # Implement the logic to write to the I2C bus
        self.bus.write_i2c_block_data(self.DRVADDR, reg, [value>>8, value&0xff])

        print(f"WRITE: reg 0x{reg:0x} -> 0b{value:016b}")



    def clear_faults(self) -> None:
        """
        Clear faults by writing 0xFF to the Fault Register.
        """
        self.write(self.FaultReg, 0xFF)


    def set_SpeedCtrl(self, speed: float, override: bool = True) -> bool:
        """
        Set the speed of the motor.

        Args:
            speed (float): Speed of the motor (0-100%).
            override (bool): Override (Binary) - True by default. Override analogue/PWM input.
        Returns:
            bool: True if successful.
        """
        val = (0b1 << 15) if override else 0b0
        val |= int(511.0 * self._crop(speed, 0.0, 100.0)/100.0)
        self.write(self.SpeedCtrl, val)
        return True

    def enable_motor(self):
        """
        Enable the motor by writing 1 to the motor enable bit (15th bit) in the control register (0x60).
        """
        control_reg = self.read(self.EECTRL)
        control_reg &= ~(1 << 15)
        self.write(self.EECTRL, control_reg)

    def disable_motor(self):
        """
        Disable the motor by writing 0 to the motor enable bit (15th bit) in the control register (0x60).
        """
        control_reg = self.read(self.EECTRL)
        control_reg |= 1 << 15
        self.write(self.EECTRL, control_reg)


    def set_shadow_mode(self):
        """
        Set Shadow Register mode by enabling the 12th bit in the EepromProgramming5 register.
        This sets the EEPROM into the shadow mode.
        """

        # Read the current value of the EepromProgramming5 register
        eeprom_reg5 = self.read(self.EepromProgramming5)
        # Set the 12th bit to 1 to enable shadow mode
        eeprom_reg5 |= self.EepromProgramming5_ShadowMode
        # Write the modified value back to the EepromProgramming5 register
        self.write(self.EepromProgramming5, eeprom_reg5)
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

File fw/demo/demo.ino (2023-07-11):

// KV = 0.00358

#include <Wire.h>

int led = 13;         // the PWM pin the LED is attached to
int brightness = 0;  // how bright the LED is
int fadeAmount = 5;  // how many points to fade the LED by

#define ADDR_DRV 0b1010010
#define ADDR_DRV_W 0b1010011



#define Fault_Reg 0x00 //
#define MotorSpeed_Reg 0x01 //
#define DeviceIDRevisionID_Reg 0x08
#define EEPROM_Access_Code_Reg 0x31
#define EEPROM_EeReady_Reg 0x32
#define EEPROM_Iindividual_Access_Adr_Reg 0x33
#define EEPROM_Individual_Access_Write_Data_Reg 0x34
#define EEPROM_Access_Reg 0x35
#define EECTRL_Reg 0x60


// Funkce pro zápis dvou bytů do registru I2C zařízení
void writeTwoBytes(uint8_t reg, uint8_t data1, uint8_t data2) {
  Wire.beginTransmission(ADDR_DRV);
  Wire.write(reg);     // Adresa registru
  Wire.write(data1);   // První byte dat
  Wire.write(data2);   // Druhý byte dat
  Wire.endTransmission();
  delay(100);
}

// Funkce pro čtení dvou bytů z registru I2C zařízení
void readTwoBytes(uint8_t reg, uint8_t& data1, uint8_t& data2) {
  Wire.beginTransmission(ADDR_DRV);
  Wire.write(reg);     // Adresa registru
  Wire.endTransmission();

  Wire.requestFrom(ADDR_DRV, 2);  // Požadavek na čtení dvou bytů

  if (Wire.available() >= 2) {
    data1 = Wire.read();   // První byte dat
    data2 = Wire.read();   // Druhý byte dat
  }
}


uint16_t read_twoByte(int address, unsigned char r){
  Wire.beginTransmission(address);
  Wire.write(r);
  Wire.endTransmission(false);
  Wire.requestFrom(address, 2);
  unsigned int lsb, msb;
  if (Wire.available() >= 2){
    msb = Wire.read();
    lsb = Wire.read();
  }
  //Wire.endTransmission(false);
  return ((msb << 8) | lsb);
}

void write_twoByte(int address, unsigned char r, uint16_t data){
  // uint16_t begin = 0;
  // begin = read_twoByte(address, r);
  delay(100);

  Wire.beginTransmission(address);
  Wire.write(r);
  Wire.write((data >> 8));
  Wire.write(data & 0xFF);
  Wire.endTransmission(true);
  
  // delay(100);
  // uint16_t end = 0;
  // end = read_twoByte(address, r);
  // Serial.printf("reg 0x%04X: 0x%04X -> 0x%04X -> 0x%04X \r\n", r, begin, data, end);
}

  uint16_t i = 0;


// the setup routine runs once when you press reset:
void setup() {

  // declare pin 9 to be an output:
  pinMode(led, OUTPUT);
  Wire.begin();        // join i2c bus (address optional for master)
  Wire.setClock(100000);

  Serial.begin(115200);
  Serial.println("Hello!");


  // Serial.println("EEPROM PROG");
  // write_twoByte(ADDR_DRV, 0x35, 0b0001000000000000);    // EEPROM SHADOW


  // Serial.println(".......");


//   uint16_t CFG1 = 0;

//   CFG1 |= 0b0111010; // RMShift, RMValue - Motor phase resistance 0.8 Ohm
//   CFG1 |= 0b1 << 7; // Half-cycle adjust
//   CFG1 |= 7 << 8;  // Pocet polu motoru
//   CFG1 |= 0b00 << 12; // FG open-loop select
//   CFG1 |= 0b11 << 14; // Spead spctrum modulation control
  
//   write_twoByte(ADDR_DRV, 0x90, CFG1);



//   uint16_t CFG2 = 0;
//   CFG2 |= 0x6c; // 4, comutation advance value
//   CFG2 |= 0b0 << 7; // Commutation advance mode
//   CFG2 |= 0b0011000 << 8; // Kt value 
//   write_twoByte(ADDR_DRV, 0x91, CFG2);


//   uint16_t CFG3 = 0;
//   CFG3 |= 0b000; // Braking mode
//   CFG3 |= 0b000 << 3; // Open-loop rampup
//   CFG3 |= 0b10 << 6; // Open-loop current
//   CFG3 |= 0b00 << 8;
//   CFG3 |= 0b0 << 10;
//   CFG3 |= 0b0 << 11;
//   CFG3 |= 0b1 << 12; // Hysteresis for BEMF
//   write_twoByte(ADDR_DRV, 0x92, CFG3);


//   uint16_t CFG4 = 0;
//   CFG4 |= 0b111; // algin time
//   CFG4 |= 0b11111 << 3; // Open to close loop
//   CFG4 |= 0b011 << 8;
//   CFG4 |= 0b0 << 11;
//   CFG4 |= 1 << 14; //  Accel range selection
//   write_twoByte(ADDR_DRV, 0x93, CFG4);


//   uint16_t CFG5 = 0;
//   CFG5 |= 0b1;
//   CFG5 |= 0b000 << 1;  // HW current limit 
//   CFG5 |= 0b010 << 4;   // SW current limit
//   CFG5 |= 0b000000 << 8; // Lock5 - LOCK0
//   CFG5 |= 0b01 << 14; // Limit current when overtemp
//   write_twoByte(ADDR_DRV, 0x94, CFG5);


//   uint16_t CFG6 = 0;
//   CFG6 |= 0b10;
//   CFG6 |= 0b11 << 2;
//   CFG6 |= 0b100 << 4;
//   CFG6 |= 0b1 << 7; // Transfer to Open-loop
//   CFG6 |= 0b1 << 8; // Hi-z
//   CFG6 |= 0b11 << 12; // KT detect threshold
//   write_twoByte(ADDR_DRV, 0x95, CFG6);

//   //write_twoByte(ADDR_DRV, 0x92, 0b1010000);
//   //write_twoByte(ADDR_DRV, 0x92, 0b0000000100000000);

//   //write_twoByte(ADDR_DRV, 0x93, 0b1101110001010);
//   //write_twoByte(ADDR_DRV, 0x93, 0b000000100001011);

//  // write_twoByte(ADDR_DRV, 0x94, 0b11111110101111);
//   //write_twoByte(ADDR_DRV, 0x94, 0b000000000000110);

//   //write_twoByte(ADDR_DRV, 0x95, 0b11000101110111);
//   //write_twoByte(ADDR_DRV, 0x95, 0b11110101000011);

//   write_twoByte(ADDR_DRV, 0x96, 0b101101010);
//   //write_twoByte(ADDR_DRV, 0x96, 0b101100010);
  



//   Serial.println("......................");

//   //Serial.println("CONFIG1");
//   //write_twoByte(ADDR_DRV, 0x90, 0x003A);

//   Serial.println("IPDPos, VoltageSupply");
//   write_twoByte(ADDR_DRV, 0x05, 0x0067);  // 0x0067 - 12V


//   Serial.println("Current");
//   //write_twoByte(ADDR_DRV, 0x04, 0x015);
//   delay(100);



//   Serial.println("SPEED");
//   write_twoByte(ADDR_DRV, 0x30, 0x8003);


write_twoByte(ADDR_DRV, 0x35, 0x1000); // Write 0b0001000000000000 (0x1000) to 0x35 arduino
write_twoByte(ADDR_DRV, 0x60, 0x8000); // Write 0b1000000000000000 (0x8000) to 0x60 arduino
write_twoByte(ADDR_DRV, 0x20, 0x3851); // Write 0b0011100001010001 (0x3851) to 0x20 arduino
write_twoByte(ADDR_DRV, 0x21, 0x2d2d); // Write 0b0010110100101101 (0x2d2d) to 0x21 arduino
write_twoByte(ADDR_DRV, 0x90, 0xc7bb); // Write 0b1100011110111011 (0xc7bb) to 0x90 arduino
write_twoByte(ADDR_DRV, 0x91, 0x183b); // Write 0b0001100000111011 (0x183b) to 0x91 arduino
write_twoByte(ADDR_DRV, 0x92, 0xff); // Write 0b0000000011111111 (0x00ff) to 0x92 arduino
write_twoByte(ADDR_DRV, 0x93, 0x58ff); // Write 0b0101100011111111 (0x58ff) to 0x93 arduino
write_twoByte(ADDR_DRV, 0x94, 0x6010); // Write 0b0110000000010000 (0x6010) to 0x94 arduino
write_twoByte(ADDR_DRV, 0x95, 0x3f93); // Write 0b0011111110010011 (0x3f93) to 0x95 arduino
write_twoByte(ADDR_DRV, 0x96, 0x480a); // Write 0b0100100000001010 (0x480a) to 0x96 arduino
write_twoByte(ADDR_DRV, 0x60, 0x0); // Write 0b0000000000000000 (0x0000) to 0x60 arduino
write_twoByte(ADDR_DRV, 0x30, 0x8008); // Write 0b1000000000001000 (0x8008) to 0x30 arduino
//write_twoByte(ADDR_DRV, 0x30, 0x8010); // Write 0b1000000000010000 (0x8010) to 0x30 arduino
write_twoByte(ADDR_DRV, 0x00, 0xffff); // Write 0b1111111111111111 (0xffff) to 0x00 arduino



}

// the loop routine runs over and over again forever:
void loop() {
  i += 1;
  //Serial.println(i);
  // set the brightness of pin 9:
  analogWrite(led, brightness);

  // change the brightness for next time through the loop:
  brightness = brightness + fadeAmount;

  // reverse the direction of the fading at the ends of the fade:
  if (brightness <= 0 || brightness >= 255) {
    fadeAmount = -fadeAmount;
  }
  // wait for 30 milliseconds to see the dimming effect
  delay(30);


  uint16_t val = read_twoByte(ADDR_DRV, 0x00);
  Serial.println(val, BIN);
  write_twoByte(ADDR_DRV, 0x00, 0xffff);

  // uint16_t current = read_twoByte(ADDR_DRV, 0x04);
  // if(current >= 1023){
  //   current -= 1023;
  // }
  // current = 3*current/512;
  // Serial.println(current);

  Serial.println(read_twoByte(ADDR_DRV, 0x06), HEX);

  //  write_twoByte(ADDR_DRV, 0x30, 0x8001);


  //write_twoByte(ADDR_DRV, 0x35, 0b0001000000000000);    // EEPROM SHADOW

  //write_twoByte(ADDR_DRV, 0x30, 0x101);





}

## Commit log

2023-06-30 schematics and layout improvements
    [DRV10975V01.kicad_pcb, DRV10987V01.kicad_pcb, DRV10987V01.kicad_sch]
2023-06-30 Update actions products
    [DRV10987V01-B_Adhesive.dxf, DRV10987V01-B_Courtyard.dxf, DRV10987V01-B_Cu.dxf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]
2023-06-30 update silkscreen, add 5v indicator
    [DRV10987V01.kicad_pcb, DRV10987V01.kicad_sch]
2023-06-30 Zmena strany sroubu
    [DRV10987V01.kicad_pcb]
2023-06-30 uprava napajeni 3v3
    [DRV10987V01.kicad_pcb, DRV10987V01.kicad_sch]
2023-06-30 repair silkscreen
    [DRV10987V01.kicad_pcb]
2023-06-30 Edit PCB and schema
    [DRV10987V01.kicad_pcb, DRV10987V01.kicad_sch]
2023-07-04 Editing component values
    [DRV10987V01.kicad_sch]
2023-07-04 Editing B.FAB
    [DRV10987V01.kicad_pcb]
2023-07-11 prvni verze, kde se kontinuelne motor toci
2023-07-11 demo arduino
2023-07-26 add notebook for Kt value determinating, add sample measurements of nanotec motors
    [df45l024053-a2_fast.csv, df45l024053-a2_slow.csv, df45m024053-a2_fast.csv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]
